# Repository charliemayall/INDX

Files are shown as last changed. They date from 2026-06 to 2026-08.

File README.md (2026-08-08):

# INDX Wiki

> The community knowledge base for the Bondtech INDX, an induction-based automatic tool changer for open-platform XY-head 3D printers.

---

## Table of Contents

**Part 1: What is INDX?**

1. [What is INDX?](#what-is-indx)
2. [How It Works](#how-it-works)
3. [Kits & What's in the Box](#kits--whats-in-the-box)
4. [Supported Printers](#supported-printers)
5. [Technical Specifications](#technical-specifications)
   - [Part Cooling](#part-cooling)

**Part 2: Getting Started**

6. [Requirements & Preparation](#requirements--preparation)
7. [Installation](#installation)
   - [Hardware Installation](#hardware-installation)
   - [Firmware Configuration](#firmware-configuration)
     - [Klipper / Kalico](#klipper)
       - [INDX macro files](#indx-macro-files)
       - [Mainsail RESUME coexistence](#mainsail-resume-coexistence)
       - [Automated dock X measurement](#automated-dock-x-measurement-built-in)
       - [Homing override](#homing-order-important)
     - [RRF (RepRapFirmware)](#rrf-reprapfirmware)
   - [Initial Startup](#initial-startup)

**Part 3: Configuration**

8. [Configuration](#configuration)
   - [Dock Position Calibration](#dock-position-calibration)
     - [Finding dock_y](#finding-dock_y-y-fully-seated-position)
     - [Finding dock_x](#finding-dock_x-x-tool-centre)
   - [Tool Offsets](#tool-offsets)
     - [Method 1: Print and adjust](#method-1-print-and-adjust-free-no-extra-hardware)
     - [Method 2: Nudge](#method-2-nudge-automatic-requires-small-hardware)
     - [Method 3: Nozzle camera + CAL_01/02/03](#method-3-nozzle-camera-most-precise-xy-higher-cost)
     - [Z offset: CAL_Z](#z-offset-calibration)
   - [Temperature & Induction Settings](#temperature--induction-settings)
   - [Speed & Acceleration](#speed--acceleration)

**Part 4: Day-to-day Use**

9. [Using INDX](#using-indx)
   - [Loading Filament into Tools](#loading-filament-into-tools)
   - [Performing Tool Changes](#performing-tool-changes)
   - [Slicer Setup](#slicer-setup)

**Part 5: Designing for INDX**

10. [Designing for INDX](#designing-for-indx)
    - [Dock Design](#dock-design)
    - [Part Cooling (custom)](#part-cooling-1)
    - [CAD Files & Templates](#cad-files--templates)

**Part 6: Maintenance, Support & Community**

11. [Maintenance](#maintenance)
    - [Nozzle clog: cold pull procedure](#nozzle-clog-cold-pull-procedure)
12. [Troubleshooting](#troubleshooting)
13. [FAQ](#faq)
14. [Community & Contributing](#community--contributing)

---

**Part 1: What is INDX?**

---

## What is INDX?

INDX (INduction Dynamic eXtruder) is Bondtech's automatic tool-changer system for FDM 3D printers. It enables printing with multiple materials, colors, or nozzle sizes in a single print, with near-zero purge waste and tool changes in around 14 seconds. Run two tools or ten; scale your setup as far as your build space allows.

Unlike filament-switcher systems, INDX is a true tool changer: each tool carries its own filament directly. There is no shared filament path and no purge block required.

Unlike traditional mechanical tool changers, INDX uses wireless induction heating, so the passive tools contain **no wires, no heaters, no thermistors, and no electronics**. This makes each tool dramatically cheaper and mechanically simpler.

INDX is sold by Bondtech as a **Development Kit** for open CoreXY printers. Prusa Research has built an official first-party integration for the **CORE One** and **CORE One L**, sold directly through Prusa.

| | INDX Development Kit | Prusa CORE One / CORE One L |
|---|---|---|
| **Sold by** | Bondtech ([bondtech.se](https://www.bondtech.se)) | Prusa Research ([prusa3d.com](https://www.prusa3d.com)) |
| **For** | Most CoreXY printers with open firmware | Prusa CORE One / CORE One L |
| **Setup** | Self-managed (community-supported) | Plug-and-play |
| **Smart Head** | See [bondtech.se](https://www.bondtech.se) | See [prusa3d.com](https://www.prusa3d.com/applications/prusa-3d-printers-with-bondtech-indx_243519/) |
| **Passive Tools** | See [bondtech.se](https://www.bondtech.se) | See [prusa3d.com](https://www.prusa3d.com/applications/prusa-3d-printers-with-bondtech-indx_243519/) |

This wiki focuses on the **INDX Development Kit** and community integrations. For the Prusa integration, refer to [Prusa's documentation](https://www.prusa3d.com/applications/prusa-3d-printers-with-bondtech-indx_243519/).

---

## How It Works

INDX is built around two components: a single active **Smart Head** that stays on the gantry, and a set of interchangeable **Thin Passive Tools** parked in a dock.

### Smart Head

The single active unit that travels on the gantry. Contains all expensive and active components:

- **Induction coil (IN)**: wirelessly heats the nozzle of whichever passive tool is currently mounted on the Smart Head.
- **IR thermopile sensor**: reads nozzle temperature without physical contact. Also reports ambient temperature and nozzle surround temperature for monitoring.
- **Dynamic eXtruder (DX)**: self-adjusting dual-drive extruder with automatic tension mechanism.
- **Load cell**: used for sensing tool/nozzle touch.
- All wiring, electronics, and motion stays here; nothing transfers to the passive tools

### Thin Passive Tools

Interchangeable tools parked in a dock within reach of the gantry. Each tool contains a filament path and a specially designed nozzle, and nothing else. No wires, no heaters, no thermistors, no electronics. Heat is delivered wirelessly by the Smart Head's induction coil when the tool is picked up; the tool cools passively when deposited back in the dock.

Two variants are available, both built from hardened steel:

- **CHT (Core Heating Technology)**: splits filament into three strands internally for faster melting and higher flow rates. The standard choice for most materials including abrasive-filled filaments. Available in common sizes.
- **Standard (non-CHT)**: straight-through melt zone with lower back-pressure, optimized for soft flexible filaments (TPU, TPE).

Tools are held in the Smart Head by a high-precision **Maxwell coupling** (a 3-point kinematic coupling that self-aligns the tool to the exact same position every time it is picked up), ensuring micron-level repeatability on every tool change. In practice this means you calibrate your tool offsets once, and they stay correct across thousands of tool changes.

### Tool Change Sequence

1. Smart Head moves to the dock and deposits the current tool
2. Smart Head picks up the next tool
3. Induction coil heats the new nozzle to printing temperature (~4-10 seconds)
4. Printing resumes

**Total tool change time: ~14 seconds**, depending on temperature delta, priming, and travel distance.

Because every material runs in its own dedicated nozzle, there is no cross-contamination between materials; purging is not required. The only material used after a tool change is a small **prime** at the start of printing: when a nozzle heats up, the filament in the melt zone re-melts and pressure needs to be rebuilt before extrusion is consistent. Priming pushes a small amount of filament through to establish that pressure, ensuring the first line of print is correctly extruded. Because each tool also cools passively when separated from the Smart Head, oozing is minimal.

---

## Kits & What's in the Box

### Development Kit

The INDX Development Kit comes as a **base kit** (the core hardware you need to get started) plus **tools** and **accessories** you choose to match your printer and setup.

#### What's in the box

Every Development Kit includes:

| Component | Description |
| --- | --- |
| **Bondtech INDX Smart Head** | The active unit: induction coil, contactless IR temperature sensor, DX extruder, and all electronics. One per printer. **Does not include a Thin Passive Tool**; tools are ordered separately. |
| **Bondtech INDX Link Board** | USB/CAN bridge between your host computer and the Smart Head. Includes 330 mm AWG18 power cables with horseshoe connectors for PSU screw terminals. A USB cable from the Link Board to your host is not included; see [Link Board](#link-board) for requirements. |
| **Crimp & connector kit** | Crimps and connectors for terminating accessories to the Bondtech INDX PCB: part cooling fan, LED, endstop, and USB devices. |

#### Tools

Thin Passive Tools are the interchangeable tool heads that do the actual printing. Choose quantity, nozzle type, and nozzle size when ordering. You need at least one tool to print, and one per material or color you want to run simultaneously.

| Option | Nozzle sizes | Best for |
| --- | --- | --- |
| **CHT (Core Heating Technology)** | 0.4 / 0.5 / 0.6 / 0.8 / 1.0mm | Most materials: PLA, PETG, ABS, ASA, PA, abrasive-filled filaments |
| **Standard (non-CHT)** | 0.25 / 0.4mm | Flexible filaments (TPU, TPE) and sensitive composites |

See [Thin Passive Tools](#thin-passive-tools) in the Technical Specifications for full details on each variant.

#### Accessories

Select the accessories that match your printer when ordering:

| Accessory | Options | Notes |
| --- | --- | ----- |
| **Bondtech INDX Link Cable** | Choose length | XT30 2+2 cable (24V, GND, CAN+, CAN−) with a shield connected to GND on the Link Board, from the Link Board to the Smart Head. Red/black wires carry power, yellow/white carry CAN H/L. Choose the length that fits your wiring run. See note below. |
| **Tool Dock** | Pre-made SLS hardware or STL/STEP files | Bondtech sells ready-made docks for common Makerbeam/1515 extrusion. Or download the files and print your own. |
| **X-Carriage adapter** | MGN12H option for 6mm belts, or download files | Required to mount the Smart Head to your carriage. Available for common CoreXY standards; check the shop or download from GitHub. |

> **What is CAN bus?** CAN bus is a communication standard that lets multiple devices share a single cable. You don't need to understand the protocol in depth; the Link Board handles it for you. In practice it means the Smart Head connects to the Link Board via just one 4-wire cable (carrying both power and data) instead of the bundle of wires a conventional toolhead needs. CAN is currently only supported on RRF; USB is used for Klipper/Kalico.
>
> **Choosing cable length:** Measure the wiring run from your Link Board mounting location to the Smart Head along the actual path the cable will travel (over the gantry, not straight-line). Add some slack. When in doubt, order longer. A cable that is too short cannot be extended, and excess length can be coiled and managed.

> **Integration note:** The Development Kit does not include a pre-configured printer profile or plug-and-play setup. You are responsible for integrating INDX with your printer's firmware and mechanics. The community provides configs and guides for common platforms; see [Supported Printers](#supported-printers) and [Community & Contributing](#community--contributing).

---

## Supported Printers

### First-party integrations

Prusa Research has built an official first-party integration for their CoreXY printers. These are sold and supported directly by Prusa, not through the INDX Development Kit.

| Printer | Status | Notes |
| --- | --- | ----- |
| Prusa CORE One | Available | Sold by Prusa Research. Plug-and-play. Supports up to 8 tools. See [prusa3d.com](https://www.prusa3d.com/applications/prusa-3d-printers-with-bondtech-indx_243519/) for details. |
| Prusa CORE One L | Coming later | First-party Prusa integration, availability timeline TBD. Supports up to 8 tools. |

### Officially supported integrations

Beyond the first-party Prusa integration, Bondtech officially supports a small set of community-built integrations for specific printers. Each comes with ready-to-print parts and the installation files needed to mount INDX on that machine. Download them from the links below.

| Printer | Designer | Files |
| --- | --- | ----- |
| Sovol SV08 OG & SV08 Max | 3DPrintDemon | [Printables](https://www.printables.com/model/1771164-official-indx-sovol-sv08-og-sv08-max-integrations) |
| Voron Trident R2 | Steve — Voron team, designer of the Trident | [Printables](https://www.printables.com/model/1761163-trident-r2-bondtech-indx-mods) |

### Community integrations

INDX runs on a wide range of CoreXY printers, far more than Bondtech could ever test and support directly. What makes that possible is community members who've done the integration work on their own printer and shared what they learned. Every config in the repo started with someone doing it for the first time.

> **What does "community" status mean?** The hardware works on that printer, but the integration guide comes from the community, not Bondtech. Some printers already have complete, verified configs on GitHub; check the repo first. Others are earlier stage. The [Bondtech Discord](https://discord.gg/XDX9jDXN6e) has channels for specific printers, which is a good place to find others running the same platform and see how far along the integration is.

| Printer | Status | Notes |
| --- | --- | ----- |
| Voron 2.4 | Community | |
| Voron Trident | Community | Trident R2 has an [officially supported integration](#officially-supported-integrations) |
| RatRig V-Core | Community | |
| Sovol | Community | SV08 OG / SV08 Max have an [officially supported integration](#officially-supported-integrations) |
| Custom CoreXY | Community | Any CoreXY with open firmware; see [Requirements](#requirements--preparation) |

**Your printer isn't listed?** If you've got INDX running on it, that integration belongs here. Submit a pull request on [github.com/BondtechAB/INDX](https://github.com/BondtechAB/INDX) and you'll save the next person hours of work. See [Contributing a printer integration](#contributing-a-printer-integration) for what to include.

---

## Technical Specifications

*Specifications are preliminary and subject to change.*

### Smart Head

| Specification | Value |
| --- | ----- |
| Maximum operating voltage | 24V |
| Maximum nozzle temperature | 300°C |
| Maximum ambient operating temperature | 60°C |
| Flow rate | 40mm³/s *(measured at 220°C with 25°C ambient; lower rates achievable depending on nozzle size)* |
| Nozzle heat-up time | ~4-8 seconds |
| Tool change time | ~14 seconds *(highly dependent on temperature, priming, and travel distance)* |
| Power consumption | ~60W |
| Tool change mechanism | Maxwell coupling (3-point kinematic) |
| Heater type | Induction coil |
| Temperature sensor | Wireless & contactless IR thermopile |
| Nozzle sensor | Load cell (bi-directional) |
| Extrusion system | Direct Drive |
| Filament pre-tension | Self-adjusting (DX extruder, dual-drive with automatic tensioning) |
| Extruder chassis material | Aluminium |
| Cowling material | SLS-printed PA12 |
| Minimum tool center-to-center distance | 34mm bare; **41mm** with Bondtech part cooling solutions |
| Weight | 345g *(including one tool)* |
| Dimensions | See [reference geometry](#cad-files--templates) |

### Part Cooling

INDX uses a modular part cooling system. Cooling solutions snap onto the outside of the Smart Head cowlings, making it easy to swap between setups without tools. Three options are supported:

| Option | Description |
| --- | --- |
| **Dual 40×10 fans** | Two axial fans mounted symmetrically for balanced airflow around the nozzle |
| **CPAP** | High-flow airflow from a remote CPAP blower unit, routed via a flexible tube to the Smart Head, keeping weight off the gantry |

The right choice depends on your materials and print speed requirements. The dual 40×10 connect to the part cooling fan output on the Bondtech INDX PCB. The CPAP blower is a remote unit mounted elsewhere on the printer and connects to your main board instead; only the airflow tube routes to the Smart Head.

Printable ducts for both options are available in [CAD Files & Templates](#cad-files--templates).

### Bondtech INDX PCB

The Bondtech INDX PCB is mounted inside the Smart Head and is the central electronics board for the system.

**Electronics**

| Specification | Value |
| --- | ----- |
| Stepper driver | TMC2240 |
| Stepper run current | 0.6A |
| Extruder rotation distance | 5.7mm |
| Built-in accelerometer | LIS2DW |
| Built-in rotary encoder | AS5047D (magnetic) |
| Built-in load cell | *(specifications to be confirmed)* |

**Connectors**

| Connector | Pins | Notes |
| --- | ---- | ----- |
| Motor | Coil A+, Coil A−, Coil B+, Coil B− | DX extruder stepper motor |
| Fan | TACHO, FAN+, GND | Supports tachometer feedback |
| LED | 5V (VBUS), NP OUT, GND | NeoPixel compatible |
| Endstop | 3V3, SIGNAL, GND | 3.3V logic level |
| USB | VBUS, DP+, DP−, GND, GND | Supports accessories such as camera or Beacon probe scanner |
| CAN termination jumper | — | Enable/disable CAN bus termination |
| CAN Reset jumper | — | Puts the board into DFU mode for firmware flashing; remove after flashing |
| Communication switch | CAN / USB | Selects between CAN-FD and USB communication modes; must match the switch position on the Link Board |

**Status LEDs**

| Label | Colour | Meaning |
| ----- | --- | --- |
| VIN | Blue | 24V power present |
| 3V3 | Green | 3.3V onboard regulator active |
| ACTIVITY | Green | CAN-FD bus activity (other than regular time-sync messages) |
| STATUS | Red | Flashes at ~1Hz in sync with the main board = CAN time sync OK; rapid continuous flashing = no CAN sync; startup error codes (see table below) |

On first boot or after a failed flash, the STATUS LED may flash a startup error code rather than the normal 1Hz pattern. The pattern is: slow blinks (group 1) pause, then fast blinks (group 2). If this happens, reflash the firmware.

**Startup error codes**

| Error | Slow blinks | Fast blinks | Description |
| ----- | --- | --- | --- |
| ErrorTempMin | 1 | 1 | Measured temperature too low |
| ErrorTempMax | 1 | 2 | Measured temperature too high |
| ErrorTempAmbientMin | 1 | 3 | Ambient temperature too low |
| ErrorTempAmbientMax | 1 | 4 | Ambient temperature too high |
| ErrorTempDiff | 1 | 5 | Requested temperature differs significantly from measured temperature |
| ErrorHeatMax | 2 | 1 | Heater on at max power for too long |
| ErrorHeatInput | 2 | 2 | Heater enable request active for too long |
| ErrorInternalTemp | 5 | 3 | IR sensor self-test failed at boot |
| ErrorInternalUart | 5 | 4 | Internal UART fault |
| ErrorInternalEnable | 5 | 5 | Internal enable fault |

**Front INDX LED states**

The Smart Head uses a NeoPixel-compatible LED array on the front face to communicate its current state during normal operation. These are the same LEDs that display startup error codes.

| State | Colour | Pattern |
| ----- | --- | --- |
| Heating | Amber (RGB 255, 191, 0) | Breathing at 0.5 Hz (sine); brightness starts at 0 and increases as temperature approaches target |
| Cold / at ambient | Green | Solid |
| At target temperature | Amber | Solid |
| Cooling down from hot | Blue | Solid |
| DFU (firmware update) mode | Blue | Blinking |
| Load cell transient (filament gripped) | Purple | Single fast flash (~200 ms), then returns to previous state; effect is suppressed while the stepper motor is energised |

**FFC cable warning**

The Smart Head contains two PCBs (INDX VF PCB and INDX MCU PCB) connected by 20-way FFC (Flexible Flat Cable) connectors. If you ever need to disconnect and reconnect them during servicing:

- Insert the cable straight; inserting at an angle is easy to do and will short pins. Powering up with a shorted FFC will likely damage the board.
- The latch direction on the INDX MCU PCB FFCs is counter-intuitive: the latch is **unlocked when up**. After inserting the cable, push the latch **down toward the PCB** to lock it.

### Link Board

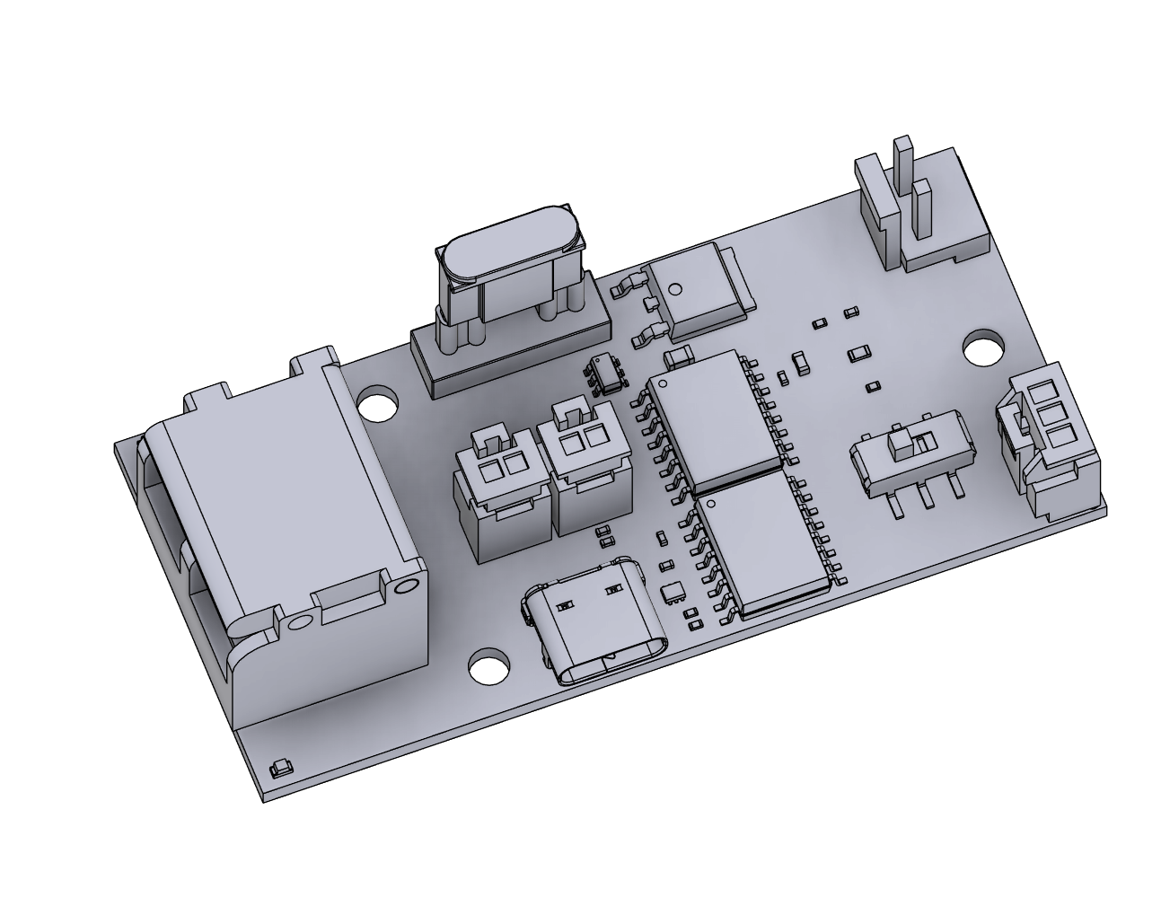
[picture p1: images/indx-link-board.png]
Bondtech INDX Link Board


The Link Board is a required component of every INDX Development Kit setup. It sits between your host computer and the Smart Head, acting as the USB/CAN bridge and providing several protection features that make the connection stable and safe.

**Why the Link Board is required**

The Link Board caps USB communication speed to **12 Mbps (Full Speed)**. While this is lower than the theoretical USB 2.0 maximum, it is intentional: Full Speed USB is dramatically more stable in electrically noisy printer environments than High Speed (480 Mbps). In practice this means fewer dropouts and disconnects, and a much more reliable connection to the Smart Head.

**Protection features**

| Feature | What it does |
| --- | --- |
| **USB isolator** | Electrically isolates the Smart Head from your host computer. Any electrical fault or noise on the printer side cannot travel back through the USB cable to your Raspberry Pi or PC. |
| **Reverse polarity protection** | Prevents damage if the 24V power input is connected with reversed polarity. |
| **4A fuse** | Protects the power input. If something goes wrong on the 24V side, the fuse blows before damage can propagate further. |

**Communication switch**

The Link Board has a switch to select between **USB** and **CAN** communication modes. This must match the switch position on the INDX MCU PCB inside the Smart Head — both boards must be set to the same mode, or the connection will not work. See [Switch configuration](#3-wiring) for reference images showing the correct switch positions on the Smart Head side.

**USB cable (not included)**

A USB cable from the Link Board to your host computer is not included and must be sourced separately. Requirements:

- **Data cable, not a charge-only cable.** Charge-only cables omit the data lines entirely and will not work. Verify the cable is rated for data transfer before using it.
- **Correct impedance.** The cable must meet USB signal integrity requirements. Cheap or poorly made cables can cause dropouts even at Full Speed. Use a cable from a reputable brand.
- **Total USB run ≤ 2 meters.** The combined length of your USB cable (host to Link Board) and your INDX Link cable (Link Board to Smart Head) must not exceed 2 meters. Plan your cable routing and Link cable length selection with this in mind.

**Specifications**

| Specification | Value |
| --- | ----- |
| Host connection | USB-C |
| Printer-side connection | Link cable to Bondtech INDX PCB |
| Input power | 24V + GND from PSU |
| Included power cables | AWG18, 330mm, horseshoe connectors for PSU screw terminals |
| USB speed | 12 Mbps (Full Speed) |
| Fuse rating | 4A |
| Max total USB run | 2 meters (USB cable + Link cable combined) |

### Thin Passive Tools

All Thin Passive Tools are built from hardened steel, contain no electronics or wiring, and use induction heating via the Smart Head. Two variants are available:

**CHT (Core Heating Technology): Standard choice for most materials**

Uses Bondtech's patented CHT internal geometry, which splits filament into three thinner strands for faster melting and higher flow rates. Recommended for PLA, PETG, ABS, ASA, PA, and abrasive-filled filaments (Carbon Fiber, Glass Fiber). Not recommended for soft flexible filaments.

| Specification | Value |
| --- | ----- |
| Available nozzle sizes | 0.4 / 0.5 / 0.6 / 0.8 / 1.0mm |
| Material | Hardened steel |
| Compatible filament diameter | 1.75mm |
| Maximum nozzle temperature | 300°C |
| Electronics | None |
| Weight | 25g |

**Standard (non-CHT): For flexible and sensitive materials**

Uses a straight-through melt zone with minimal back-pressure, specifically optimized for soft flexible filaments (TPU, TPE) and sensitive composites. Built to the same hardened steel standard, so it handles abrasive filaments equally well.

| Specification | Value |
| --- | ----- |
| Available nozzle sizes | 0.25 / 0.4mm |
| Material | Hardened steel |
| Compatible filament diameter | 1.75mm |
| Maximum nozzle temperature | 300°C |
| Electronics | None |
| Weight | 25g |

---

**Part 2: Getting Started**

---

## Requirements & Preparation

If you've built a Voron or a similar CoreXY printer from scratch, you have the skills needed to install INDX. The process involves editing Klipper config files, SSH access to your host computer, and careful mechanical alignment. Nothing beyond what a first-time Voron builder will have already done.

### Printer Requirements

For the Development Kit, your printer must meet these minimum requirements:

- **Motion system:** CoreXY, H-bot, Markforged, Cartesian XY-head, or similar. Supported: any motion system where the toolhead moves in XY and Z is handled by the bed or gantry — i.e. CoreXY (not cross-gantry), H-bot, Markforged, and independent-axis Cartesian (XY-head, e.g. Ender 5). Not supported: bed-slinger Cartesian (XZ-head), where the bed moves in Y, or Positron-style machines.
- **Firmware:** Kalico (recommended — native INDX support built in), Klipper, or RepRap Firmware (RRF)
- **Gantry clearance:** 50mm X, 44mm Y. Total toolhead height is ~152mm including strain relief. Additional clearance is required for umbilical and filament management.
- **Dock mounting area:** Each dock is ~70mm tall, 28.5mm wide (X), and 25mm deep (Y). Minimum tool center-to-center spacing is 34mm bare, or 41mm when using the Bondtech part cooling solutions.
- **Wiring:** 24V from the PSU to the Link Board (AWG18 horseshoe-connector cables included). Host computer to Link Board via USB-C or CAN. Link Board to Smart Head via INDX Link Cable (XT30 2+2, carries 24V, GND, CAN+/−, and shield).
- **Print volume impact:** Depends on printer geometry. Printers with sufficient Y overtravel may lose nothing. With a well-designed integration the worst case is 28.5mm of Y travel; avoid designs that exceed this.

### Electrical Requirements

INDX uses two boards: the **Bondtech INDX PCB** (inside the Smart Head) and the **INDX Link Board**.

**Bondtech INDX PCB**

The Bondtech INDX PCB is the central electronics board inside the Smart Head. It consists of two parts connected internally:

- **INDX VF PCB**: handles induction heating, contactless IR temperature sensing, and the heatsink fan
- **INDX MCU PCB**: handles all processing and communication: extruder motor control, accelerometer, load cell, CAN-FD communication, and the external connectors

All electronics are pre-installed inside the Smart Head; no internal wiring required. The Smart Head connects to the Link Board via a single INDX Link Cable (24V, GND, CAN H/DP+, CAN L/DN−, shield to GND) and exposes the following connectors:

- **Motor**: 4-pin, drives the DX extruder (TMC2240 driver). Pin 1 Coil A+, Pin 2 Coil A−, Pin 3 Coil B+, Pin 4 Coil B−
- **Endstop**: 3-pin, 3.3V logic level. Pin 1 3V3, Pin 2 SIGNAL, Pin 3 GND
- **Fan**: 3-pin, supports tachometer feedback. Pin 1 TACHO, Pin 2 FAN+ (PWM 24V), Pin 3 GND
- **LED**: 3-pin NeoPixel. Pin 1 5V (VBUS), Pin 2 NP OUT, Pin 3 GND
- **USB**: 5-pin, supports accessories such as a camera or Beacon probe scanner. Pin 1 VBUS (5V), Pin 2 DP+, Pin 3 DP−, Pin 4 GND, Pin 5 GND
- **Built-in accelerometer**: for resonance measurement and automatic input shaper calibration in Klipper
- **CAN termination jumper**: fitting the jumper enables the 120 Ω end-of-line termination resistor. Fit only on boards at the physical ends of the CAN bus.
- **CAN reset jumper**: Klipper: short the jumper to enter DFU mode for flashing. RRF: fit the jumper for CAN reset (also resets the CAN address). See the [Duet INDX Toolboard documentation](https://docs.duet3d.com/en/Duet3D_hardware/Duet_3_family/INDX_Toolboard).
- **Status LEDs**: 3V3, VIN, STATUS, ACTIVITY

Induction heating and contactless IR temperature sensing are handled internally by the INDX VF PCB; no additional wiring or configuration needed.

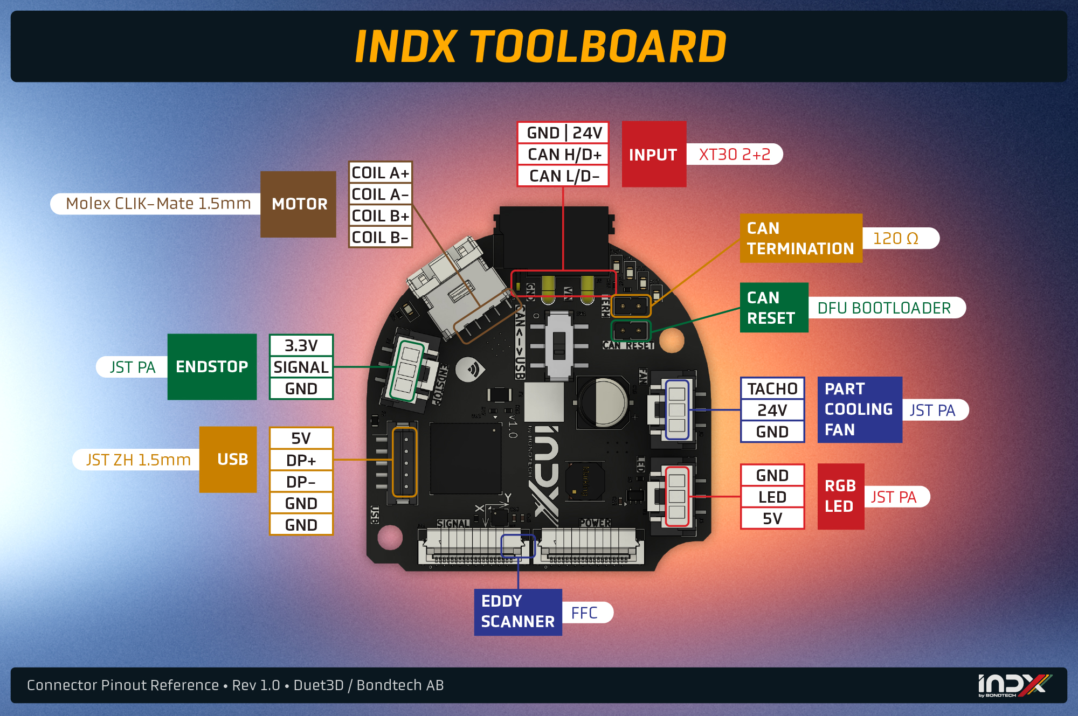
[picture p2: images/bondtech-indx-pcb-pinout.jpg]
Bondtech INDX PCB pinout


**Klipper pin → port mapping** (not exposed in RRF)

| Function | Port(s) |
| --- | --- |
| Motor | STEP `PB12` · DIR `PB23` · ENN `PB4` · CS `PA10` · SPI1 SCLK `PA5` / MOSI `PA4` / MISO `PA7` |
| Endstop | `PA9` |
| Part cooling fan | FAN `PA1` · TACHO `PA0` |
| Heatsink fan | FAN0 `PA21` · TACHO `PA20` |
| Neopixel | `PA8` |
| Eddy scanner | ldc_int `PB10` · ldc_clk `PB11` · temp_ldc `PB9` |

**Link Board**

The Link Board is required and bridges your host computer to the Smart Head. For full details on protection features, the communication switch, and USB cable requirements, see [Link Board](#link-board) in the Technical Specifications.

For wiring purposes:

- Requires **24V and GND** from your printer's power supply; connect using the included power cables (AWG18, 330 mm, pre-terminated with horseshoe connectors for screw terminal PSUs)
- Connects to the Smart Head via the INDX Link Cable
- Connects to your host computer via USB (cable not included — see [Link Board](#link-board) for requirements)
- The communication switch on the Link Board must match the switch on the INDX MCU PCB; both must be set to the same mode

**Power**

- The system runs on **24V**
- The Link Board is powered by a direct 24V/GND connection from your PSU
- Power is then passed through the Link cable (24V, GND, CAN+/D+, CAN−/D-) from the Link Board to the Smart Head; no additional PSU connection needed at the Smart Head

**Mainboard compatibility**

- Works with any printer running a Raspberry Pi, similar host computer or Duet board
- The Link Board connects to the host via CAN/USB; the host handles CAN/USB communication to the Bondtech INDX PCB

### Software Requirements

- **Kalico (recommended):** native INDX support is built in — nothing to install on the host, and the MCU firmware ships with Kalico. See [Firmware Configuration](#klipper).
- **Klipper (mainline):** add the [`indx_klipper`](https://github.com/BondtechAB/indx_klipper) module (installed with its `install.sh`), which brings the same INDX support to a stock Klipper install. See [Firmware Configuration](#klipper).
- RRF: RepRapFirmware **3.7.0-alpha (2026-02-10) or later**, required on both the main board and the Bondtech INDX PCB.
- Slicer: Any slicer with multi-filament or multi-color support

### Tools Required

| Tool | Use |
| ---- | --- |
| Hex keys | Smart Head, X-carriage adapter, and dock mounting |
| Crimping tool | Optional; only needed if connecting accessories (fan, LED, endstop, or USB devices) to the Bondtech INDX PCB |

### Skills Assumed

- Editing Klipper config files (`.cfg` syntax, adding sections, restarting Klipper)
- SSH access to your host computer (the [Connect via SSH](#connect-to-your-printer-via-ssh) section covers this if you need a refresher)
- Crimping JST and similar connectors

### What to Have Ready Before Starting

- A working printer, homed, printing, and confirmed stable before you begin
- Kalico (or Klipper / RRF) installed and running on your host computer
- SSH access to your host computer confirmed
- Spool holders and filament routing planned for the number of tools you intend to run

---

## Installation

> **Note:** These are general installation guidelines using the Bondtech-sold hardware as an example. Because INDX works across many different CoreXY printers, exact details (screw sizes, adapter geometry, carriage type, dock placement) will vary by printer. For printer-specific integration guides, check the [github.com/BondtechAB/INDX](https://github.com/BondtechAB/INDX) repository and the community resources in [Community & Contributing](#community--contributing).

### Hardware Installation

#### 1. Install the Smart Head

The Smart Head replaces your printer's existing toolhead entirely. It mounts to the X-axis carriage using a two-part system:

1. **X-carriage adapter**: bolts onto your carriage
2. **Smart Head**: attaches to the X-carriage adapter with 4 bolts

**X-carriage adapters** are available in two ways:

| Source | Material | Notes |
| --- | --- | --- |
| Bondtech (shop) | SLS-printed Nylon 12 GF | Common MGN12 carriage options available to purchase |
| GitHub / community | User-printed | STL/STEP files on [github.com/BondtechAB/INDX](https://github.com/BondtechAB/INDX); print your own for less common setups |

If your carriage configuration isn't covered by Bondtech's sold options, check the GitHub repo for a community-contributed adapter or print your own from the provided files. A printable MGN12H adapter (6mm belts) is available in [CAD Files & Templates](#cad-files--templates). Community-made X-carriage designs that meet quality standards will be included in the official repo. If you're designing your own, see [CAD Files & Templates](#cad-files--templates) for the reference geometry files.

> **Before you start:** Remove your existing hotend, part cooling fan, and any toolhead PCB or wiring mounted on the carriage. The Smart Head replaces all of this.

**Step 1: Mount the X-carriage adapter to the carriage**

Route and attach the belts behind the X-carriage, then attach the X-carriage adapter to your carriage block using the screws specified for your adapter. Tighten firmly but do not overtighten.

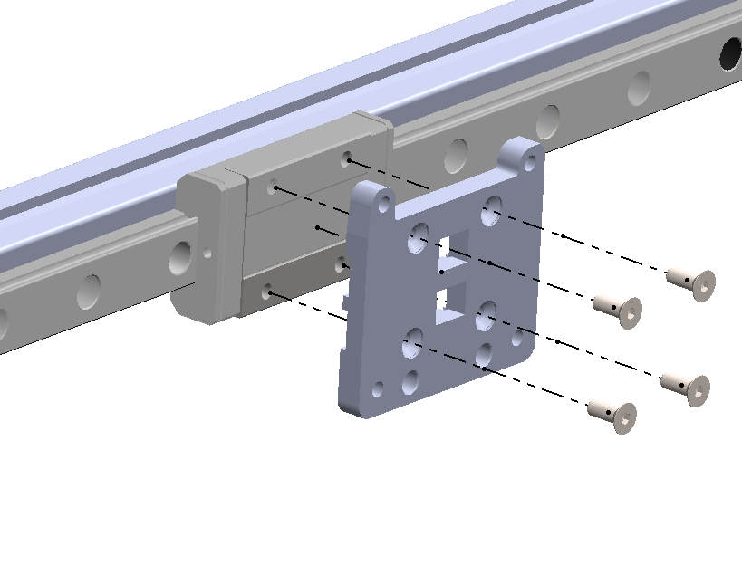
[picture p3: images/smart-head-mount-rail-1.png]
INDX MGN12H adapter mounting to rail, exploded view


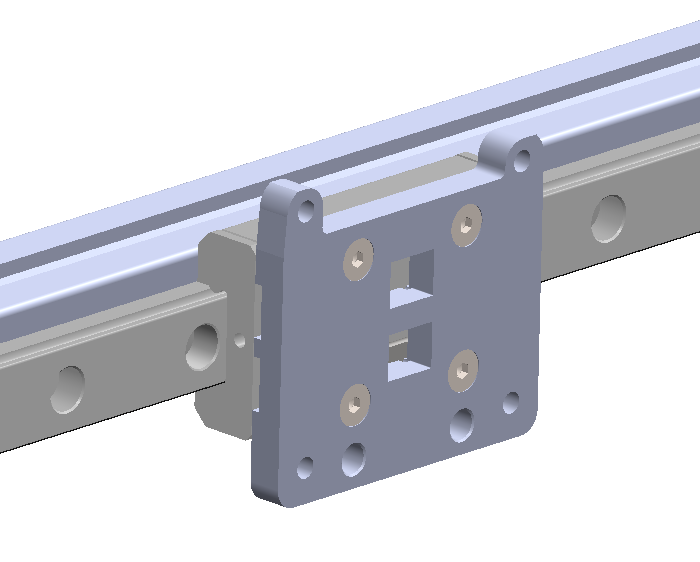
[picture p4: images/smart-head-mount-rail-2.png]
INDX MGN12H adapter mounted on rail


**Step 2: Place the Smart Head onto the adapter**

Slide the Smart Head onto the X-carriage adapter so the mounting faces are flush.

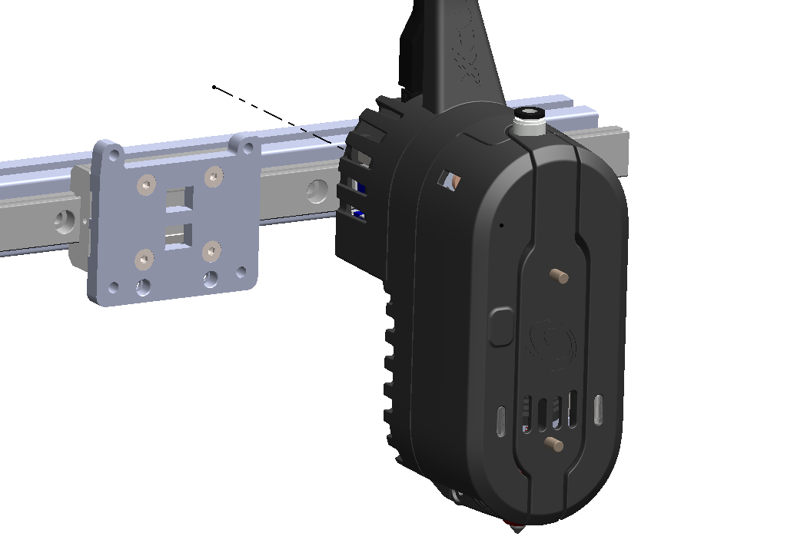
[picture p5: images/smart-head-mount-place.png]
Smart Head placed on X-carriage adapter


**Step 3: Secure the Smart Head**

Fasten the Smart Head to the adapter using 4 screws as specified for your adapter. Tighten firmly but do not overtighten.

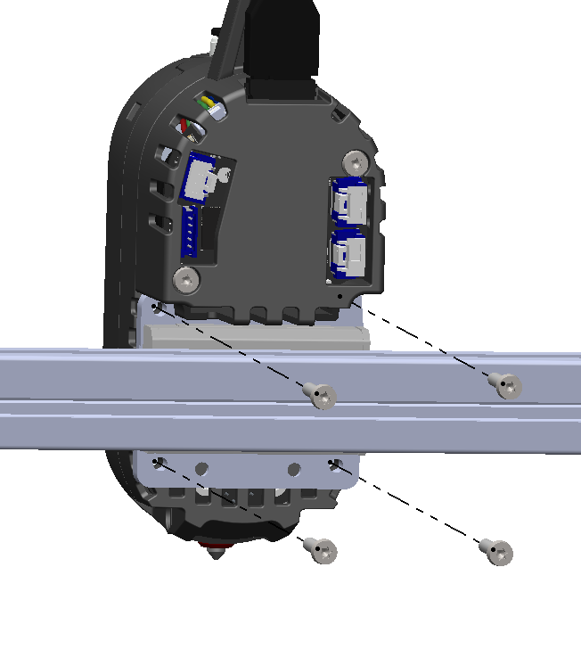
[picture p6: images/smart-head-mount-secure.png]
Smart Head secured, rear view


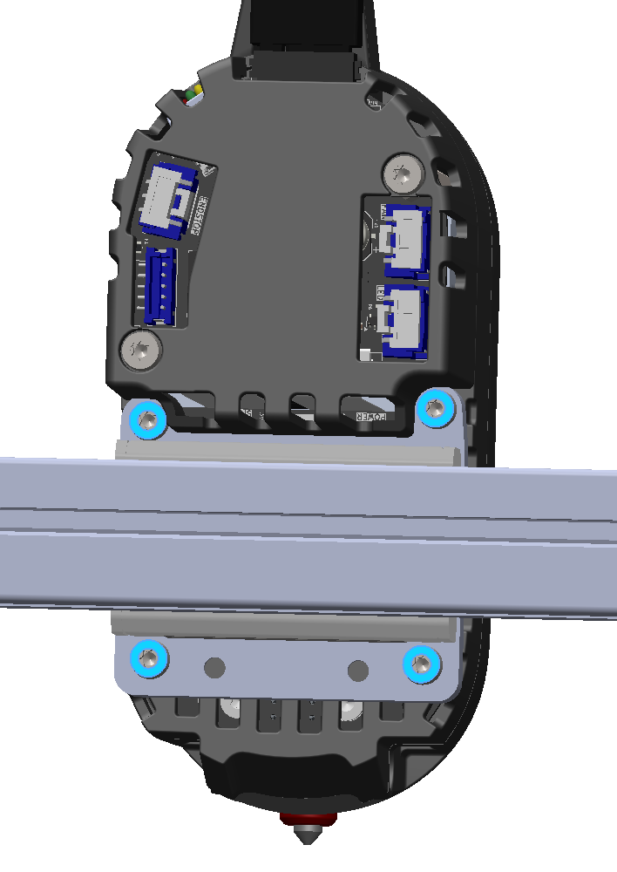
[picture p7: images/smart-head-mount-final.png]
Smart Head fully installed, front view


The Smart Head is now installed on the carriage.

**Attach part cooling**

Part cooling solutions snap onto the outside of the Smart Head cowlings. Attach your chosen cooling solution now before mounting the dock.

**Installing the fan shroud clip**

1. Loosen the screw that holds the INDX Front Cover.

   Loosen front cover screw

2. Use an M3×8 screw to secure the INDX Front Cover together with the fan shroud clip.

   Fan shroud clip installed

3. With the clip installed, attach the fan shroud to the Front Cover. The shroud has an upper tab that locates into a slot at the top of the Front Cover (highlighted in blue). Align the tab with the slot, then rotate the bottom of the shroud inward until it seats in position.

   Fan shroud mounted

#### 2. Mount the Dock

The dock can be positioned anywhere within the gantry's travel range, but the Smart Head must be able to face the docked tools directly to pick them up. The right location depends on your printer's layout.

**Frame requirement**

The dock must be mounted to a rigid bar or frame element; the dock hardware alone cannot be free-standing. Most CoreXY printers have an extrusion or crossbar that works for this. If your printer does not have a suitable mounting point, you will need to add one before proceeding.

The Bondtech-sold dock hardware is designed to mount on **15×15 aluminium extrusion**. If you are printing your own dock from the GitHub files, design your mounting to suit your frame.

> ⚠️ **Critical:** The dock has strict positioning requirements that must be met for reliable tool changes. Incorrect placement will cause failed pickups. See the critical requirements below before mounting.

**Dock options:**

| Source | Type | Mounting |
| --- | --- | --- |
| Bondtech (shop) | SLS-printed Nylon 12 GF | Common options for 15×15 aluminium extrusion |
| GitHub | Reference design + community designs | Print yourself, or adapt for your frame |

Community-contributed dock designs will be added to [github.com/BondtechAB/INDX](https://github.com/BondtechAB/INDX) as they are developed. If you design a dock for an unlisted printer or frame, consider submitting it. See [Dock Design](#dock-design) for geometry constraints and design requirements before you start.

**Critical dock positioning requirements**

**Height**

The dock must be positioned so that a parked tool sits **2mm higher** than it does when held in the Smart Head. This offset is what allows the Smart Head to pick up and deposit tools cleanly.

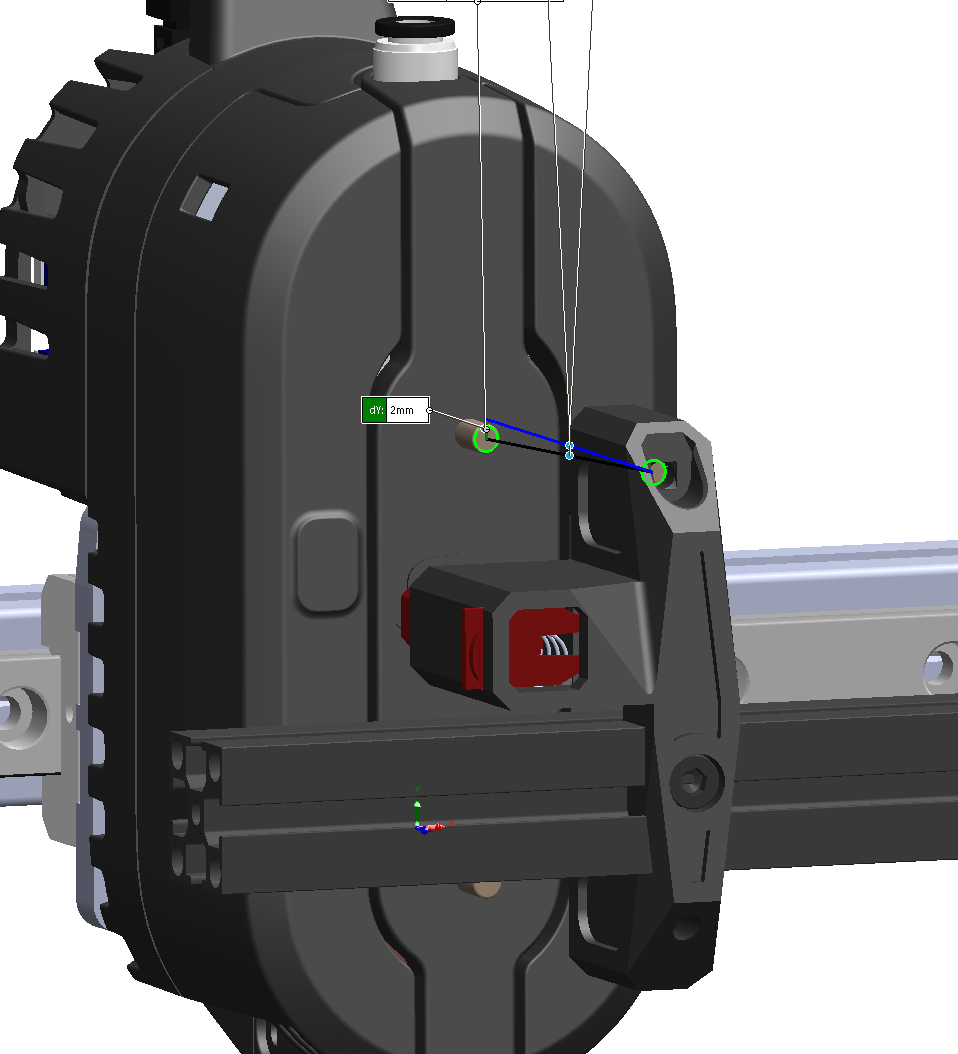
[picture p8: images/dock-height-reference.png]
Dock height reference: 2mm offset between docked and picked-up tool position


**Alignment method**

Use the printable alignment jig ([`INDX_Dock_calibration_tool.stl`](CAD/STL/INDX_Dock_calibration_tool.stl)) placed over the nozzle tool in the toolhead to set the correct height. The printer does not need to be powered on for this step; you are setting the physical dock height manually.

1. Place the printed alignment jig over the tool magnets while the tool is in the smart head.

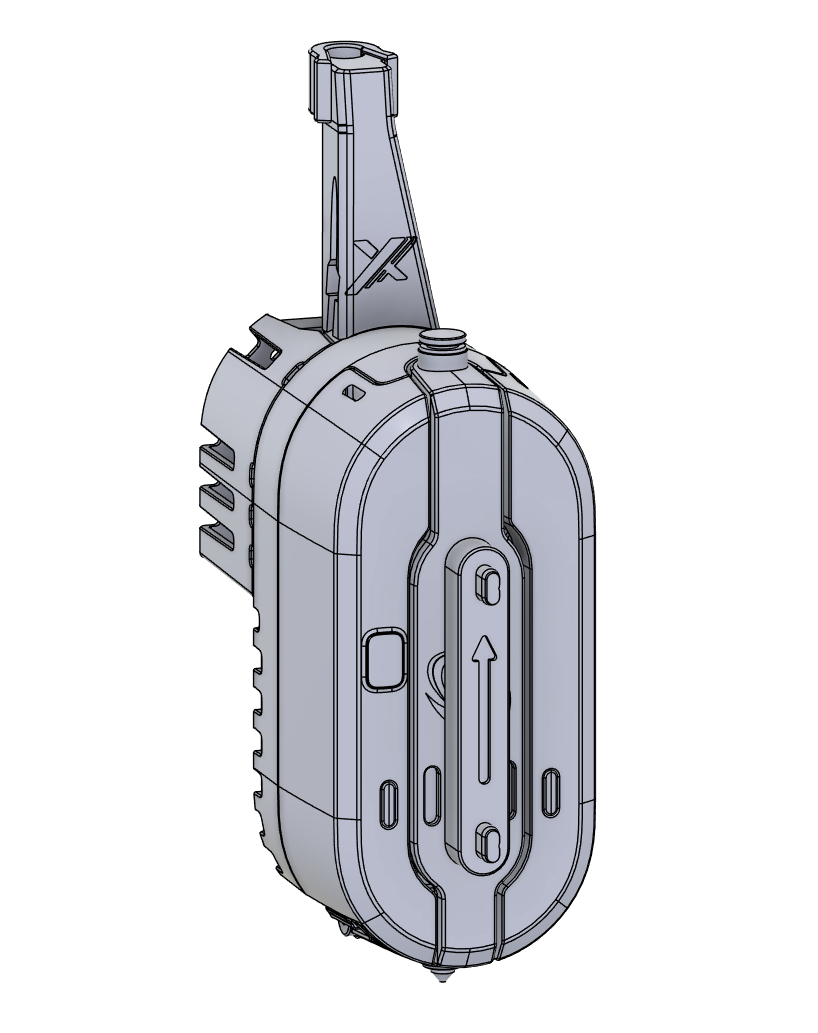
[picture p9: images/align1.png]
Extra magnet placed on the INDX front trigger surface
   

2. Loosen the bar holding screws in order to let it be adjusted up and down, then slide the smart head toward the tool dock and make sure the alignment jig enters the magnet holes smoothly without the smart head nodding from mechanical strain.

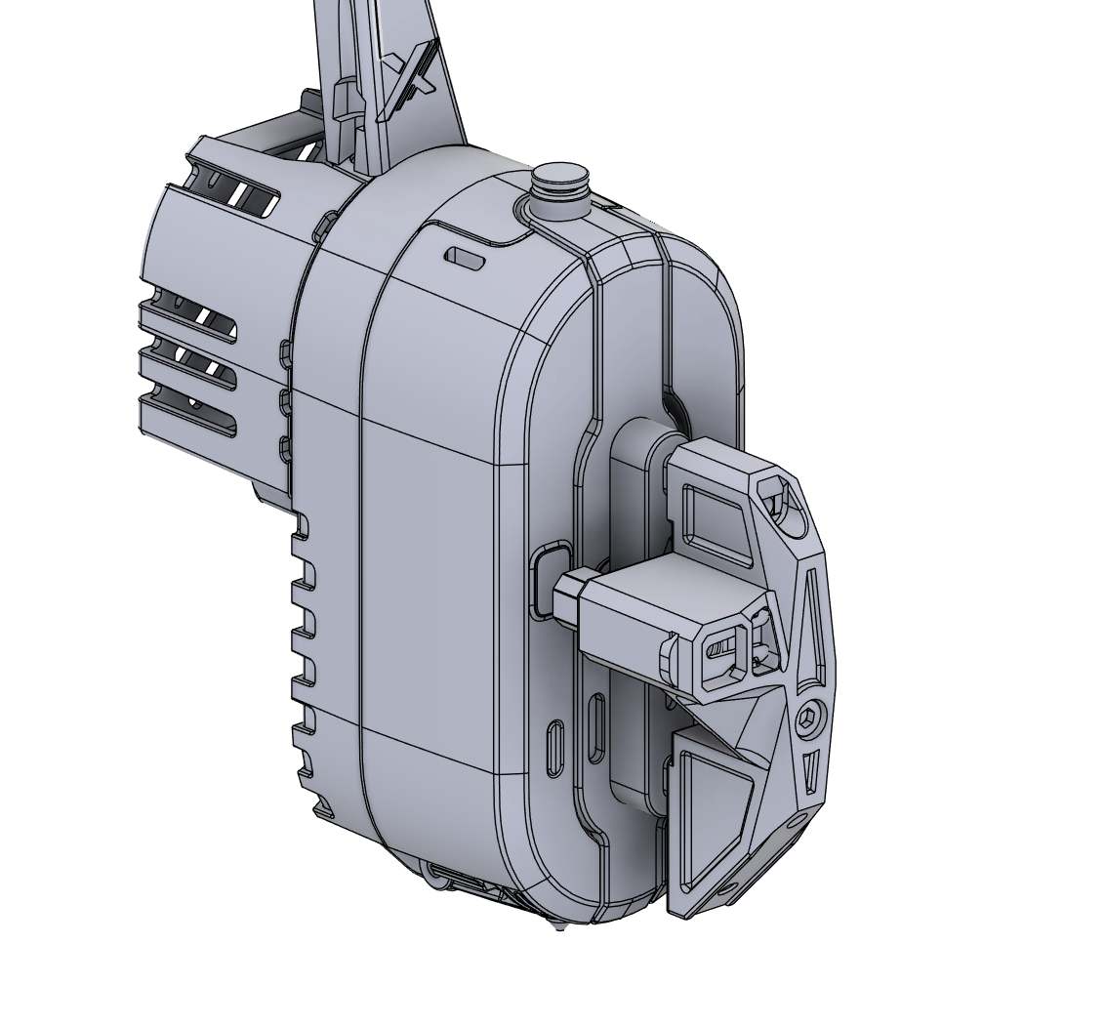
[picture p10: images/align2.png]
Magnet aligned with tool holder magnet
   

3. Secure the dock bar at that height

#### 3. Wiring

Wiring up the Smart Head is unusually simple for a toolhead. On a conventional setup, you're running individual wires for the heater cartridge, thermistor, hotend fan, stepper motor, and any probes or sensors, each terminated, routed, and managed separately. With INDX, all of that is internal: the induction coil, IR temperature sensor, and heatsink fan are all handled inside the Smart Head with no external connections required. The only cable you run to the Smart Head is a single INDX Link Cable, four wires carrying 24V power and data.

The included **Link Board** acts as the bridge between your host computer and the Smart Head. Your host computer connects to the Link Board via USB (cable not included — see [Link Board](#link-board) for requirements), the Link Board connects to the Smart Head via the INDX Link Cable, and the Link Board receives 24V power from the PSU via the included AWG18 cables. That's the entire wiring run.

**Overview of connections:**

```
24V PSU ──────────────────────────────────────────────┐
                                                       │ 24V + GND
Raspberry Pi / host computer                           ▼
    │                                             Link Board
    └── USB ──────────────────────────────────────────►│
                                                       │
                                                       └── Link cable (24V, GND, CAN H/DP+, CAN L/DN−) ──► Bondtech INDX PCB (inside Smart Head)
                                                                                                           │
                                                                                                           ├── Motor (Coil A+, Coil A−, Coil B+, Coil B−)
                                                                                                           ├── Fan (TACHO, FAN+, GND)
                                                                                                           ├── LED (5V, NP OUT, GND)
                                                                                                           ├── Endstop (3V3, SIGNAL, GND)
                                                                                                           └── USB (VBUS, DP+, DP−, GND, GND)
```

**Switch configuration**

Before connecting the Link cable, set the communication mode switches on **both boards** to match: the switch on the INDX MCU PCB inside the Smart Head, and the switch on the Link Board. Both must be set to the same mode or the connection will not work.

Set both switches to **CAN** if you are using RRF. Set both to **USB** if you are using Klipper or Kalico.

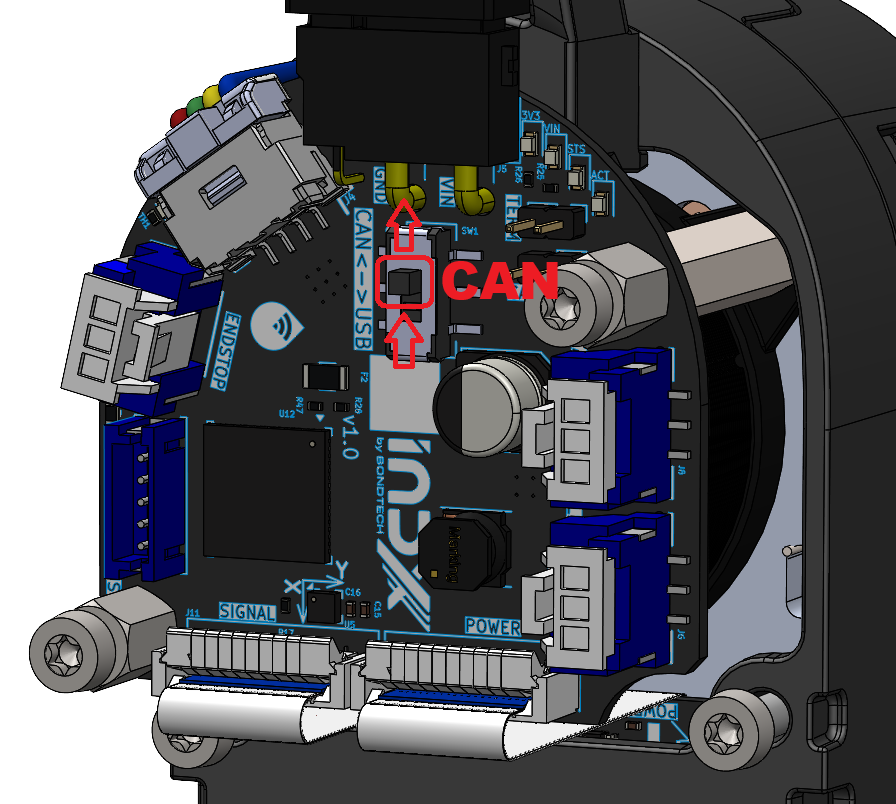
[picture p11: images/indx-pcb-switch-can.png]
INDX MCU PCB switch set to CAN mode

*Switch set to CAN mode*

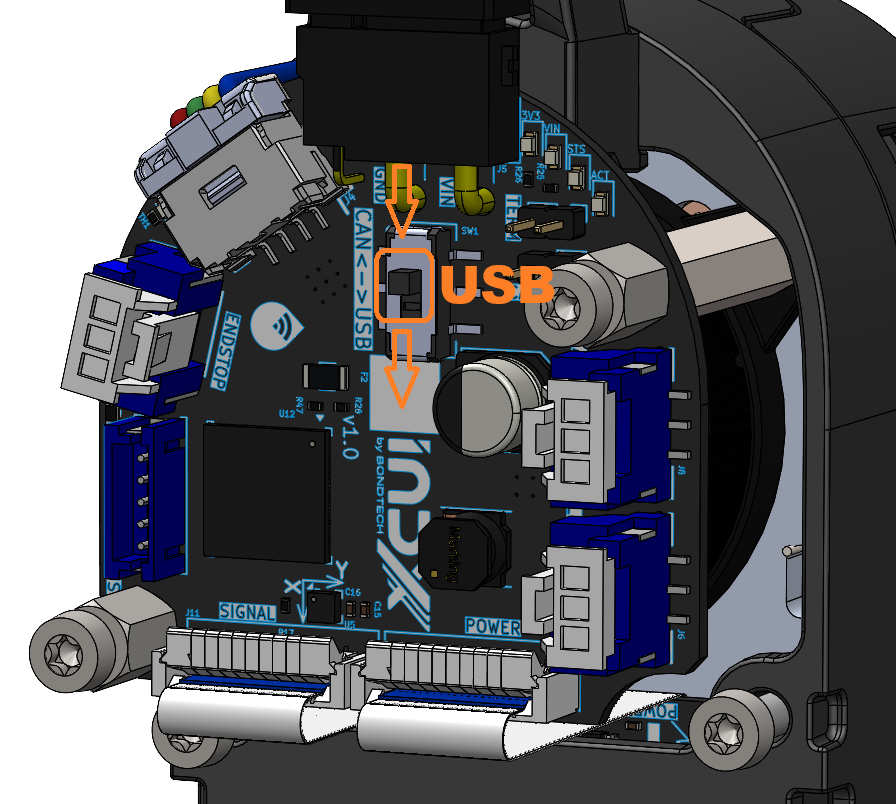
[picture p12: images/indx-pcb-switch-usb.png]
INDX MCU PCB switch set to USB mode

*Switch set to USB mode*

#### 4. Flash the Bondtech INDX PCB

The Bondtech INDX PCB needs to be flashed with the correct firmware before the Smart Head can communicate with your printer. The flashing process differs depending on your firmware; follow the section for your setup.

##### Klipper / Kalico

Flashing is done over SSH from your computer into the Raspberry Pi (or other host computer) running Kalico or Klipper.

**What you need**

- **PuTTY**: a free SSH client for Windows. Download it from [putty.org](https://www.putty.org/).
- Your printer's **IP address**: find this in your router's device list, or check the display on your host if it shows one. You can also use the hostname (e.g. `mainsailos.local` or `fluidd.local`) if your network supports it.

###### Connect to your printer via SSH

1. Open PuTTY
2. Enter your printer's IP address (or hostname) in the **Host Name** field
3. Make sure **Port** is set to `22` and **Connection type** is `SSH`
4. Click **Open**
5. Log in with your printer host credentials; the default username for most Klipper distributions is `pi` (Mainsail OS / FluiddPI) with the password you set during setup

You should now have a terminal prompt on your printer's host computer.

**Enter the bootloader**

Flashing happens while the Bondtech INDX PCB is in bootloader mode. If the board already has firmware, put it into the bootloader by fitting the **CAN RESET jumper** on the INDX MCU PCB while powering the board up. In bootloader mode the board enumerates on the host as a Microchip USB device (vendor `04d8`, product `e483`), identified as **"INDX Toolboard Bootloader"** by Bondtech AB. Confirm it is present with:

```bash
lsusb | grep 04d8:e483
```

**Kalico (recommended)**

Kalico ships with native INDX support built in — both the host module and the MCU firmware are part of the Kalico source tree, so there is nothing extra to install. Build and flash from your Kalico directory (usually `~/klipper`):

```bash
cd ~/klipper
KCONFIG_CONFIG=board_configs/bondtech_indx_usb.config make
KCONFIG_CONFIG=board_configs/bondtech_indx_usb.config make flash FLASH_DEVICE=04d8:e483
```

The `board_configs/bondtech_indx_usb.config` build config is included with Kalico. It preselects the SAME51 MCU, USB communication, and the INDX heater feature, so you don't need to run `make menuconfig`.

**Klipper (mainline)**

Mainline Klipper does not include INDX support. Add it with the `indx_klipper` module, then build and flash:

```bash
git clone https://github.com/BondtechAB/indx_klipper.git
cd indx_klipper
./install.sh /home/pi/klipper        # adjust the path to your Klipper install
make
make flash FLASH_DEVICE=04d8:e483
```

Once flashing is complete, remove the CAN RESET jumper (if you fitted one), power-cycle the Smart Head, and proceed to firmware configuration.

##### RRF (RepRapFirmware)

For RRF, flash and configure the Bondtech INDX PCB following the [Duet INDX Toolboard documentation](https://docs.duet3d.com/en/Duet3D_hardware/Duet_3_family/INDX_Toolboard).

#### 5. Load Passive Tools into the Dock

**Verify the Tool Dock Activator**

Before loading tools, check that the Tool Dock Activator is correctly installed. It is a small bracket mounted upright on the 15×15 mm aluminium extrusion using an M3×10 screw and an M3 nut. It must be perfectly vertical; this is the component that triggers the INDX latch mechanism during pickup.

Tool Dock Activator mounted on extrusion

Check that it is perpendicular to the extrusion:

Tool Dock Activator vertical alignment

**Load tools into the dock**

One passive tool fits in one dock position. Tools are retained by 3×8 mm bar magnets embedded in both the tool and the dock. The magnets naturally guide the tool into the correct orientation as you bring it close; follow the magnetic pull to seat it.

Passive tool loaded in dock

> **Note:** You will set the exact dock position coordinates (`dock_y` and `t*_x`) during the calibration steps later. For now, just seat the tools; the INDX macros handle the rest once configured.

---

### Firmware Configuration

#### Klipper

INDX's host-side support provides everything your printer needs to talk to the Smart Head: the `indx` temperature sensor, induction-heater control, extruder and accessory pin mapping, and the calibration commands. How you add it depends on your firmware:

- **Kalico (recommended):** support is **built in**. There is nothing to install on the host — the `[indx]` object and the `indx` sensor type are part of Kalico, and the MCU firmware ships with it too. Once you've flashed the Bondtech INDX PCB from the Kalico tree (see [Flash the Bondtech INDX PCB](#4-flash-the-bondtech-indx-pcb)), go straight to configuring your printer.
- **Klipper (mainline):** install the [`indx_klipper`](https://github.com/BondtechAB/indx_klipper) module, which adds the same host-side support to a stock Klipper install. Clone it and run its `install.sh` (see [Flash the Bondtech INDX PCB](#4-flash-the-bondtech-indx-pcb) for the commands).

The tool-change and calibration **macros** (`T0`/`T1`…, `PARK_TOOL`, the `CAL_*` helpers) are provided by the INDX macro package — see [INDX macro files](#indx-macro-files).

**Configure your printer**

After installing the plugin, add your INDX configuration to `printer.cfg`:

Add the following to your `printer.cfg`. The `serial` path under `[mcu indxmcu]` will be unique to your board; see the note below on how to find it.

```ini
[mcu indxmcu]
# Replace the serial path below with the one from your board — see "Finding your serial path" below
serial: /dev/serial/by-id/usb-Bondtech_INDX_<your-serial-here>

[indx]
mcu: indxmcu

# These are control parameters for the induction heater — leave them at these values
pid_kp: 1.0
pid_ti: 0.0
pid_td: 0.0
pid_b: 1.0

[extruder]
sensor_type: indx  # Custom sensor type provided by the INDX plugin — reads temperature via the IR sensor on the induction board
min_temp: 0
max_temp: 350

heater_pin: indx:heater
# Induction heating uses watermark (on/off bang-bang) control, not PID.
# This works well for induction because of its very fast response time. Do not change to pid.
control: watermark
nozzle_diameter: 0.4     # Change to match your passive tool nozzle size (0.4 / 0.6 / 0.8 / 1.0)
filament_diameter: 1.75

step_pin: indxmcu:motor_step
dir_pin: indxmcu:motor_dir  # If filament feeds backwards, change to: !indxmcu:motor_dir
enable_pin: !indxmcu:motor_enable
microsteps: 32
rotation_distance: 5.7  # Pre-calibrated for the DX extruder — do not change

[tmc2240 extruder]
cs_pin: indxmcu:motor_cs
spi_software_sclk_pin: indxmcu:motor_sclk
spi_software_mosi_pin: indxmcu:motor_mosi
spi_software_miso_pin: indxmcu:motor_miso
rref: 24000  # Reference resistor value for the TMC2240 on the INDX PCB — do not change
run_current: 0.6

[fan]
pin: indxmcu:part_cooling
tachometer_pin: indxmcu:part_cooling_tacho

[neopixel indx]
pin: indxmcu:led
chain_count: 16  # Fixed for the Smart Head LED array — do not change

[gcode_button endstop]
pin: ^indxmcu:endstop
press_gcode: {action_respond_info("press")}
release_gcode: {action_respond_info("release")}

[lis2dw]
# Built-in accelerometer on the INDX PCB — used for input shaper calibration
i2c_mcu: indxmcu
i2c_bus: sercom3

[angle indx]
# Magnetic encoder that reads extruder rotation — used for precise extrusion monitoring
sensor_type: as5047d
stepper: extruder
cs_pin: indxmcu:encoder_cs
spi_bus: sercom1
```

> ⚠️ **Do not change `rotation_distance`**
>
> The `rotation_distance: 5.7` value is pre-calibrated for the DX extruder and is used by the INDX tool-change macros to calculate precise filament moves during tool changes. Changing it, even slightly, will cause incorrect filament positioning and failed tool changes. Do not treat it as a value to tune. If your extrusion multiplier needs adjusting, do it in the slicer, not here.

**Finding your serial path**

The `serial` value under `[mcu indxmcu]` is unique to your board. To find it, SSH into your printer (see [Connect to your printer via SSH](#connect-to-your-printer-via-ssh)) and run:

```bash
ls /dev/serial/by-id/
```

Copy the path that starts with `usb-Bondtech_INDX` and paste it into your config.

**Configuring multiple tools**

The `[extruder]` block above is always required and represents the Smart Head's single DX extruder. INDX passive tools are **not** separate Klipper extruders — there is only ever one `[extruder]`. Additional tools (T1, T2, …) are defined in `indx.cfg`: set `variable_tool_count` and add a `variable_t{n}_x` / `variable_t{n}_dock_y` pair per tool in the `[gcode_macro TOOL_POSITIONS]` section (see [INDX macro files](#indx-macro-files)). Per-tool XY/Z offsets come from [Tool Offsets](#tool-offsets) calibration, and per-tool nozzle sizes and temperatures are set in your slicer.

##### INDX macro files

The INDX firmware plugin provides a set of `.cfg` files you include from `printer.cfg`. Each file has a specific role:

| File | Role |
| ---- | ---- |
| `indx.cfg` | User configuration: tool positions and related settings. **The only file you need to edit.** |
| `indx-tc-macros.cfg` | Tool change logic: `CHANGE_TOOL`, `PARK_TOOL`, boot detection. Do not edit. |
| `indx-cal.cfg` | Calibration macros: dock position, XY/Z offset calibration. |
| `homing.cfg` | `[homing_override]`: Y then X, ensure a tool (T0 when possible), then Z. |
| `indx-helpers.cfg` | Optional helpers: latch lock/unlock, load-cell tool presence, RESUME wrapper for mid-print detect. Include after `indx-tc-macros.cfg`. |

Include them from your `printer.cfg`:

```ini
[include indx/indx.cfg]
[include indx/indx-tc-macros.cfg]
[include indx/indx-cal.cfg]
[include indx/homing.cfg]
[include indx/indx-helpers.cfg]   # after tc-macros; after mainsail.cfg in printer.cfg
```

Klipper allows only one `[homing_override]`. If your printer already has one (sensorless current, bed raiser, etc.), merge the INDX sequence into yours instead of including `homing.cfg` as-is.

##### Mainsail RESUME coexistence

If you use Mainsail's stock `mainsail.cfg`, it defines `[gcode_macro RESUME]`. Klipper merges duplicate section names; when `indx-helpers.cfg` is included later, INDX's RESUME (tool-detect recheck) replaces Mainsail's body. Without a printer-side patch, Mainsail's temp restore, runout gate, and `_CLIENT_EXTRUDE` never run.

INDX owns the `RESUME` command and `rename_existing: RESUME_BASE`. Move Mainsail's wrapper to `_CLIENT_RESUME` in your local `mainsail.cfg` (or a small override file included after Mainsail):

1. Rename `[gcode_macro RESUME]` to `[gcode_macro _CLIENT_RESUME]`
2. Remove `rename_existing: RESUME_BASE` from that section (INDX already renames the builtin)
3. In `CANCEL_PRINT`, change `printer['gcode_macro RESUME']` to `printer['gcode_macro _CLIENT_RESUME']`
4. In `CANCEL_PRINT`, `PAUSE`, and the renamed section body, change every `SET_GCODE_VARIABLE MACRO=RESUME` to `MACRO=_CLIENT_RESUME`
5. Keep `RESUME_BASE VELOCITY=...` at the end of `_CLIENT_RESUME`

Call chain after the patch: `RESUME` (INDX) -> optional `_RESUME_PRESENCE_*` on tool-detect fail -> `_CLIENT_RESUME` (Mainsail) -> `RESUME_BASE` (Klipper). If `_CLIENT_RESUME` is missing, INDX falls back to `RESUME_BASE` so resume still works.

After editing, run `FIRMWARE_RESTART`. `HELP` should show INDX's RESUME description.

##### Automated dock X measurement (built in)

Automated dock X measurement is **built into the INDX plugin** — there is no separate Python extra to install. The plugin registers `INDX_DOCK_MEASURE`, which energises the XY motors, homes Y then X from the dock, and derives the absolute dock position from the raw stepper counts (so it works for each tool in turn without a prior `G28`).

The `indx-cal.cfg` macros wrap this into the calibration commands you actually run:

| Command | Description |
| --- | --- |
| `CALIBRATE_DOCK_X TOOL=N` | Measures dock X for tool N via `INDX_DOCK_MEASURE` and reports the value to paste into `indx.cfg`; see [Dock Position Calibration](#dock-position-calibration) |
| `READ_DOCK_POSITION TOOL=N` | Reports the current (already-homed) X as dock X for tool N |

---

##### Homing order (important)

With a dock mounted on your printer, the default homing sequence can cause crashes. The Smart Head must move away from the dock before X is homed, and Z homing needs a seated tool (the load cell is the nozzle probe).

The INDX macro package includes a ready-to-use `[homing_override]` in `homing.cfg` that handles all of this. Its sequence, in full:

1. If Z is already known: raise to `probe_z_clearance` (set in `indx.cfg`)
2. Home Y, then move to `clearance_y` so X does not sweep into the dock
3. Home X
4. Before Z: require a seated tool (`VERIFY_TOOL_PRESENT`). If a tool is already locked, Z homes with that tool (its XY/Z offsets are re-applied before the probe). If the head is empty and the dock is usable, pick T0. If Z has never been homed, dock pickup is unsafe - seat and lock a tool by hand after load-cell calibration, then home. Empty-head Z without a known tool is refused (the load cell will not trigger without a nozzle).
5. Move to the probe XY (`probe_x` / `probe_y`, or bed centre) and home Z

`CAL_Z` still stores per-tool Z offsets relative to T0. Homing no longer requires T0 when another tool is already locked - toolchanges keep applying `tool_z + global_z`, so nozzle height stays consistent after a non-T0 Z home. Mesh or tilt after that home (as in `PRINT_START`) keeps the frame consistent.

If you use sensorless XY homing, wrap the `G28 Y` / `G28 X` steps in your usual TMC current reduce/restore (merge into the override if you already have one).

**Review your `PRINT_START` macro**

If you are migrating from a single-toolhead printer, your existing `PRINT_START` macro almost certainly heats the hotend before printing starts, something like `M104 S{first_layer_temperature}` or `M109 S{first_layer_temperature}`. With INDX, this will cause problems: there is no hotend to heat until a tool has been picked up by the Smart Head.

> ⚠️ Any hotend heating commands in your `PRINT_START` macro must come **after** the first tool pick-up. Sending a heat command before a tool is picked up will result in an error, and depending on your macro structure, may cause a crash or leave the printer in a bad state.

Review your `PRINT_START` macro and move all `M104`/`M109` (and any temperature wait commands) to after the first tool pick (`Tn` / `CHANGE_TOOL`). If you are writing a fresh macro, pick up a tool first, then heat.

#### RRF (RepRapFirmware)

Configure the Bondtech INDX PCB in RRF following the [Duet INDX Toolboard documentation](https://docs.duet3d.com/en/Duet3D_hardware/Duet_3_family/INDX_Toolboard).

### Initial Startup

Before calibrating the dock or running any tool changes, verify that the Smart Head is communicating correctly and all connected components are working. Work through these checks in order before moving anything near the dock.

### 1. Verify MCU connection

Power on your printer and open Klipper (Mainsail or Fluidd). Check the MCU status in the interface; `indxmcu` should appear as connected.

If Klipper reports a timeout or cannot connect to `indxmcu`, the most common causes are:

- **Firmware not flashed**: the most likely cause on a first startup. If you haven't flashed the Bondtech INDX PCB yet, or the flash didn't complete successfully, go back to [Flash the Bondtech INDX PCB](#4-flash-the-bondtech-indx-pcb) before continuing
- **Incorrect `serial` path**: re-run `ls /dev/serial/by-id/` via SSH and confirm the path matches what's in `[mcu indxmcu]` in your config
- **Communication mode switch** not set correctly: confirm the switch on the INDX MCU PCB is set to CAN or USB to match your wiring. See [Switch configuration](#3-wiring) for reference images
- **INDX Link Cable** not fully seated at either end

Once `indxmcu` shows as connected, proceed.

### 2. Check extruder motor direction

With no filament loaded, issue a small extrude command from the Klipper console:

```gcode
G91           ; relative mode
G1 E10 F300   ; extrude 10mm
G90           ; back to absolute
```

> **Note:** If Klipper throws a "Cannot extrude — minimum extrude temperature" error, either heat the nozzle first (`M104 S200` and wait for it to reach temperature), or — on Kalico — allow cold extrusion at runtime with `M302 P1`. Run `M302 P0` to re-enable the protection once you've confirmed motor direction. No config change or restart is needed.

The extruder gear should turn in the direction that feeds filament through the tool. If it moves the wrong way, add `!` to the `dir_pin` in your `[extruder]` config and restart Klipper.

### 3. Check part cooling fan

If you have a part cooling fan connected to the Bondtech INDX PCB, trigger it from the console and confirm it spins:

```gcode
M106 S255   ; fan full speed
M107        ; fan off
```

Skip this step if you haven't connected a fan yet.

### 4. Verify accelerometer

The Bondtech INDX PCB has a built-in accelerometer; no external ADXL345 or similar sensor needed. Confirm it is responding:

```gcode
ACCELEROMETER_QUERY
```

You should see a stream of X/Y/Z acceleration values returned in the console. If you get an error, check the `[lis2dw]` section in your config for correct `i2c_mcu` and `i2c_bus` values.

### 4a. Run input shaper calibration (optional but recommended)

With the built-in accelerometer confirmed working, you can run Klipper's resonance testing to calibrate input shaper, with no external ADXL345 needed.

**Install the required Python dependencies**

These are not installed by default on most Klipper hosts. Run this once on your Pi:

```bash
sudo apt install python3-numpy python3-matplotlib libatlas-base-dev libopenblas-dev -y
~/klippy-env/bin/pip install numpy matplotlib --upgrade
```

Then restart Klipper:

```bash
sudo systemctl restart klipper
```

**Add the resonance tester config**

Make sure your config includes a `[resonance_tester]` section referencing the built-in accelerometer and a probe point near the centre of your bed:

```ini
[resonance_tester]
accel_chip: lis2dw
probe_points:
    <X_CENTER>, <Y_CENTER>, 20    # replace with your bed centre coordinates
```

> ⚠️ The built-in accelerometer on the INDX PCB is a **LIS2DW**, not an ADXL345. Use `accel_chip: lis2dw`, not `adxl345`.

**Run the tests**

Home the printer, then run one axis at a time from the Klipper console:

```gcode
TEST_RESONANCES AXIS=X
TEST_RESONANCES AXIS=Y
```

Klipper will move the toolhead through a frequency sweep and generate resonance data. Once both axes are done, run:

```gcode
SHAPER_CALIBRATE
```

This analyses the data and recommends input shaper settings. Apply the suggested values to your `[input_shaper]` section in your config, then save and restart Klipper.

> 💡 If `TEST_RESONANCES` returns an error about missing modules, the Python dependencies above were not installed correctly. Re-run the `apt install` and `pip install` commands and restart Klipper again.

### 5. First heat-up & heater calibration

The induction heater itself is controlled by a simple **on/off (watermark) loop**, which suits induction's very fast thermal response. Separately, the INDX board builds a **thermal model** of the nozzle and tool that it uses purely for **safety monitoring** — detecting a nozzle that isn't heating as expected, a tool pulled mid-heat, or a thermal runaway (these surface as the `ErrorTempDiff` / `ErrorHeatMax` conditions). The thermal model does not drive heating; it only supervises it. Before first use this model has to be calibrated. It is a one-time procedure per tool/cooling setup; the results are written to your config with `SAVE_CONFIG`.

> ⚠️ The nozzle gets hot during calibration. Pick up a tool first (`T0`) so a nozzle is present in the coil, and keep flammable material away from the Smart Head.

Run the commands in order from the Kalico/Klipper console:

| Command | What it does |
| --- | --- |
| `INDX_CALIBRATE` | Heats the nozzle through a controlled ramp and fits the thermal-model parameters (`max_power`, `thermal_capacity`, `to_ambient_r`) |
| `INDX_FAN_CALIBRATE` | Steps the part cooling fan through several speeds and models its cooling effect on the nozzle |
| `INDX_LOAD_FILAMENT` | Loads filament and measures its heat capacity so the model accounts for the energy the filament carries away (see below) |
| `SAVE_CONFIG` | Writes the calibrated values into your `[indx]` config section and restarts |

`INDX_CALIBRATE` and `INDX_FAN_CALIBRATE` characterise the nozzle/tool and the part cooling fan — run them once per tool type and cooling setup. Because these values feed the safety model rather than the control loop, don't hand-edit them afterwards; re-run the routine if the tool type or part cooling setup changes.

**Filament heat capacity.** Different filaments carry heat away from the nozzle at different rates, so the safety model also needs to know which filament is loaded. You set this when you load filament into a tool, not during the one-time calibration above:

- **Measure it** — `INDX_LOAD_FILAMENT` feeds and primes filament while measuring the actual heat capacity, then (with `APPLY=1`) writes it to your config. Most accurate; run `SAVE_CONFIG` to keep it.
- **Set it by type** — `INDX_SET_MODEL_PARAMS FILAMENT_DENSITY=… FILAMENT_HEAT_CAPACITY=…` applies known values for a material without measuring.

The `LOAD_FILAMENT` macro wraps both of these together with tool selection — see [Loading Filament into Tools](#loading-filament-into-tools).

---

**Part 3: Configuration**

---

## Configuration

### Load cell calibration

The Smart Head's load cell senses tool/nozzle touch and is the printer's **Z probe**, so it must be calibrated before the printer can home Z.

> ⚠️ **Do this before your first Z homing.** Z homing probes the bed with the load cell, so the load cell must be calibrated before a full `G28` — and therefore before dock and [Z-offset](#z-offset-calibration) calibration. It's a first-boot, by-hand step: **X and Y are homed first** (they don't use the load cell), but the tool is seated by hand because the dock can't be reached until Z is homed.

Start with **no tool on the Smart Head** and run:

```gcode
CALIBRATE_LOAD_CELL
```

This homes X and Y, opens the latch, and tares the empty head. Now **seat a passive tool on the Smart Head by hand** — the tool **must be empty** (no filament in the extruder gears) — then lock it and calibrate against the known locking force (default 1600 g):

```gcode
CALIBRATE_LOAD_CELL_APPLY GRAMS=1600
SAVE_CONFIG
```

Prefer the console? Run `LOAD_CELL_CALIBRATE`, then `TARE` with no tool, seat an **empty** tool and lock the latch, then `CALIBRATE GRAMS=1600`, `ACCEPT`, and `SAVE_CONFIG`.

Restart, then home the printer (`G28`) — Z now probes with the load cell.

### Dock Position Calibration

Before any tool changes can happen, you need to find and save the exact dock position for each tool. Two coordinates are required per tool, both set in `indx.cfg`:

> 💡 **Dock calibration tool:** A printable jig ([`INDX_Dock_calibration_tool.stl`](CAD/STL/INDX_Dock_calibration_tool.stl)) is available to help align the dock during this process. Print it before starting.

| Variable | Meaning |
| --- | --- |
| `variable_t{n}_x` | X coordinate of the tool holder centre (mm) |
| `variable_t{n}_dock_y` | Y coordinate where the tool is fully seated (mm) |
| `variable_dock_dir` | Y sign into the dock: `-1` front (min Y), `+1` rear (max Y). Default `-1`. |

The trigger line (`dock_y - dock_dir * trigger_offset`) is derived automatically; you only set `dock_y`.

For a rear dock, set `variable_dock_dir: 1` and put `clearance_y` on the bed side of the tools.

> ⚠️ **Take this slow.** Moving the Smart Head into the dock area without verified coordinates is one of the most crash-prone steps in the entire INDX setup. A misaligned approach at speed can damage the Smart Head, the passive tools, or the dock itself.
>
> - **Always use the smallest jog increments available** (0.1 mm or less) when approaching a tool
> - **Never jog in Y toward the dock** until you are confident the X position is correct
> - **Keep your hand near the emergency stop** (or have it open in your browser) throughout this process
> - If anything looks wrong, stop immediately and re-evaluate before continuing

---

#### Finding dock_y (Y: fully seated position)

With the Smart Head holding the tool, carefully jog in Y in small increments until the tool is fully seated in the dock. When it feels fully engaged, run:

```gcode
CAL_SET_DOCK_Y
```

The console will report the current Y as `dock_y` for that tool. Paste the reported value into `indx.cfg`:

```ini
variable_t0_dock_y: -26.0   # from CAL_SET_DOCK_Y output
```

Repeat for each tool and restart Klipper to apply.

---

#### Finding dock_x (X: tool centre)

Three options; choose one:

**Option A: `CALIBRATE_DOCK_X` (automated, built in)**

Measures the absolute X position without needing a prior home, using the plugin's native `INDX_DOCK_MEASURE` (which derives the dock position from the raw stepper counts across the Y+X homing sequence).

1. `M84` (disable motors)
2. Manually slide the toolhead to the T0 dock
3. Run:
   ```gcode
   CALIBRATE_DOCK_X TOOL=0
   ```
   The macro homes Y then X and reports the measured `dock_x` for that tool. Paste it into `indx.cfg`:
   ```ini
   variable_t0_x: 0.000   # from CALIBRATE_DOCK_X output
   ```
4. For each additional tool: `M84`, slide to the dock, run `CALIBRATE_DOCK_X TOOL=N`. No `FIRMWARE_RESTART` needed between tools.
5. Once all tools are recorded, `RESTART` to apply, then `G28` to restore normal machine coordinates.

**Option B: `READ_DOCK_POSITION` (if already homed)**

If the printer is already homed, jog the Smart Head to the tool's dock X position in Mainsail or Fluidd and run:

```gcode
READ_DOCK_POSITION TOOL=0
```

Reports the current X as `dock_x` for that tool. Paste the value into `indx.cfg` (`variable_t{n}_x`) and `RESTART` to apply.

**Option C: manual**

Home the printer, jog the Smart Head to the dock X for each tool, and note the X coordinate shown in the interface. Enter it as `variable_t{n}_x` in `indx.cfg`.

> 💡 **Home regularly.** Stepper motors can lose steps if a crash or hard stop occurs, meaning the position shown in your interface may no longer match the actual toolhead position. Re-home your printer (`G28`) before recording any coordinates, and again after any crash or unexpected movement. If you suspect steps have been lost, discard any coordinates taken since the last home and start that tool's calibration over.

#### First tool change test

Once you have calibrated the dock position for at least one tool, do a controlled first pick-up to confirm it works before setting up the full multi-tool configuration.

> ⚠️ **Take this slow.** Use the smallest jog increments and keep your hand near the emergency stop throughout. If anything looks wrong, stop immediately.

1. Home the printer (`G28`)
2. Pick up the tool:
   ```gcode
   T0
   ```
3. Confirm the Smart Head locks onto the tool and the nozzle begins heating
4. Once at temperature, confirm the DX extruder can feed filament (optional: extrude a short amount manually)
5. Park the tool back in the dock:
   ```gcode
   PARK_TOOL
   ```
6. Confirm the tool deposits cleanly and the Smart Head returns to a safe position

If the pick-up or deposit fails, do not retry at speed. Go back to the dock position calibration steps above and recheck the coordinates for that tool.

---

### Tool Offsets

Each passive tool has a slightly different position relative to the Smart Head pickup point. Tool offsets must be calibrated so prints align correctly when switching tools. There are several ways to do this, ranging from free manual methods to precise hardware-assisted ones.

---

### Method 1: Print and adjust (free, no extra hardware)

The simplest approach: print a multi-tool test pattern, measure any misalignment visually or with calipers, and adjust offsets in your config manually. Repeat until aligned.

This is the lowest-cost method but also the least precise and most time-consuming. It's a good starting point if you have no other hardware available. A well-regarded starting point is the [Offset XY Dual Extruder / IDEX Calibration print](https://www.printables.com/model/129617-offset-xy-dual-extruder-idex-calibration); print it with two tools, measure any X/Y misalignment with calipers, update the offsets in your config, and reprint until they align.

Because the test print uses two tools at a time, always use T0 as your reference tool and calibrate each additional tool against it separately: first print T0 + T1, then T0 + T2, then T0 + T3, and so on. Do not try to calibrate T1 against T2 directly; everything should be referenced back to T0.

**Precision:** Low–medium | **Cost:** Free

---

### Method 2: Nudge (automatic, requires small hardware)

[Nudge](https://github.com/zruncho3d/nudge) is a low-cost contact probe that automates X/Y/Z nozzle alignment. The nozzle physically touches the probe from multiple directions; software calculates exact offsets for each tool automatically.

Nudge is highly repeatable, typically below 0.003mm standard deviation over 10 samples, and can be permanently mounted inside a heated chamber. It's a popular choice in the tool changer community.

**Precision:** High | **Cost:** Low (probe hardware + printed parts)

---

### Method 3: Nozzle camera (most precise XY, higher cost)

A nozzle-mounted or fixed camera system (e.g. [Axiscope](https://github.com/nic335/Axiscope)) lets you visually align tools with sub-micron precision. Offsets are derived from image analysis rather than physical contact.

The INDX macro package includes a built-in camera calibration workflow (`CAL_01` → `CAL_02` → `CAL_03`) that automates the offset calculation once a camera is set up.

**Workflow:**

1. Pick up T0 and jog the nozzle tip to the centre of your camera crosshair. Run:
   ```gcode
   CAL_01_SET_CAMERA_REF
   ```
   This saves the current position as the reference point.

2. For each additional tool, run:
   ```gcode
   CAL_02_PREP_TOOL_CAL TOOL=1
   ```
   The macro picks up the tool and moves it to the camera position. Re-centre the nozzle in the crosshair using the jog controls, then run:
   ```gcode
   CAL_03_SAVE_XY_OFFSET
   ```
   The offset is calculated and saved automatically. Repeat for every additional tool.

Offsets are saved as `t{n}_offset_x` / `t{n}_offset_y` and applied immediately on the next tool pick-up.

**Precision:** Very high | **Cost:** Medium–high (camera hardware)

---

### Z offset calibration

Regardless of which XY method you use, Z offsets are set automatically using the load cell.

#### Z auto-calibration: CAL_Z

`CAL_Z` probes every tool with the load cell and sets all Z offsets in one automated run. T0's probe result establishes the global Z offset.

```gcode
CAL_Z
```

Prerequisites:
- Printer homed (homes automatically if not)
- **No filament available to the extruder gears in any tool** — latch engage moves during pickup can spike load-cell readings and calibration to fail if filament is loaded.

Per tool, the macro:
1. Picks up the tool
2. Pre-probes 3× at a per-tool debris-clearing spot to clean the nozzle tip
3. Runs a convergence loop at a clean spot: probes repeatedly until the 4-sample rolling variance is below 0.005 mm, fuzzing to a new position if it stalls
4. Takes a median of 5 final samples as the result
5. Parks the tool

T0's median result sets the global Z reference. All other tools' offsets are saved as `t{n}_offset_z` relative to T0. Run `CAL_CHECK_OFFSETS` to inspect the results.

---

### Recommended approach

| Need | Recommended method |
| ---- | --- |
| Z offset only | `CAL_Z` |
| XY + Z, no extra hardware | Method 1 (print and adjust) or Method 2 (Nudge) for XY + `CAL_Z` for Z |
| Maximum XY precision | Method 3 (camera) for XY + `CAL_Z` for Z |

### Temperature & Induction Settings

Temperature is set in your slicer, the same way you would set it for any standard hotend: assign a target temperature to each filament or color in your project. INDX behaves like a normal hotend from the slicer's perspective.

The main difference from a traditional hotend is heat-up speed. A conventional heater block takes 30–60 seconds to reach printing temperature. With induction heating acting directly on the nozzle with very low thermal mass, INDX does it in around 4 seconds. That's what makes ~14-second tool changes possible.

**No induction-specific settings are required.** The induction board handles heating automatically. There are no power or frequency parameters to configure.

**Preheating is not supported and not possible.** Passive tools contain no electronics; there is nothing to preheat while a tool is parked in the dock. Do not configure standby or preheat temperatures for individual tools in your slicer; doing so may produce errors since the firmware has no way to act on them for a docked tool.

### Speed & Acceleration

Tool change motion speed and acceleration are controlled by three preset modes: **Stealth**, **Normal**, and **Sport**. Each mode sets a multiplier that is applied against the `max_velocity` and `max_accel` values defined in your `printer.cfg`. The macros read those limits at runtime, so the modes automatically scale to whatever printer they're running on, with no hardcoded numbers.

| Mode | G-code | Speed multiplier | Accel multiplier | XY stepper mode |
|---|---|---|---|---|
| **Stealth** | `MODE_STEALTH` | 20% | 20% | StealthChop (quiet) |
| **Normal** | `MODE_NORMAL` | 70% | 70% | SpreadCycle |
| **Sport** | `MODE_SPORT` | 100% | 100% | SpreadCycle |

**Stealth** runs the toolchange at 20% of your printer's configured limits. The XY steppers are switched to StealthChop, making the swap nearly silent. Useful for overnight printing or noise-sensitive environments. The trade-off is a longer toolchange duration and slightly higher stepper heat.

**Normal** is the default. It uses 70% of your printer's limits with SpreadCycle, a good balance of speed, noise, and reliability for most printers and materials.

**Sport** uses the full `max_velocity` and `max_accel` from your `printer.cfg`. This gives the fastest possible toolchange times for your specific printer. Make sure your configured limits are within what your printer can actually handle; if `max_velocity` or `max_accel` are set too high, Sport mode will expose that immediately. Input shaper should be tuned before running Sport; without it, high-acceleration toolchange moves can cause the steppers to lose steps.

Mode switching also sets StealthChop or SpreadCycle on every configured XY TMC driver (`tmc2208`, `tmc2209`, `tmc2130`, `tmc2240`, or `tmc5160`). On AWD setups, that includes `stepper_x1` and `stepper_y1` when present. The driver type is detected once at boot from your `printer.cfg`.

The active mode persists across reboots. To change it, run the macro from the console or add it to your start G-code:

```gcode
MODE_STEALTH   ; quiet/slow
MODE_NORMAL    ; default
MODE_SPORT     ; full speed
```

> **Note:** The speed limits are applied only during toolchange motion. As soon as the swap completes, the macros restore whatever velocity and acceleration limits the slicer set before the toolchange, and your print resumes at its normal print speeds.

---

**Part 4: Day-to-day Use**

---

## Using INDX

### Loading Filament into Tools

Filament can be loaded into a passive tool in three ways; try each and use what works best for your setup:

- **While the tool is in the dock**: convenient if the dock is easily accessible
- **While the tool is picked up by the Smart Head**: useful if the toolhead position is easier to reach
- **Before placing the tool in the dock**: load it on the bench, then dock it

There is no single correct method. Your printer geometry, spool placement, and personal preference will determine what works best.

**Guided loading with `LOAD_FILAMENT`**

The `LOAD_FILAMENT` macro handles the whole sequence for you: it picks up the tool, tells the safety thermal model which filament is loaded, heats to temperature, then feeds and primes.

```gcode
LOAD_FILAMENT TOOL=0 TYPE=PLA
```

- **`TOOL=<n>`** — which tool to load (it is picked up automatically).
- **`TYPE=<material>`** — applies a density + heat-capacity preset and a default load temperature. Built-in types: `PLA`, `PETG`, `ABS`, `ASA`, `PA`, `PC`, `TPU`. Edit the `filament_presets` table in `indx-cal.cfg` to add materials or tune values. Presets may also set an optional `speed` (mm/s) for the feed/prime step; `TPU` uses 2 mm/s so soft filament does not buckle during guided load.
- **`TEMP=<°C>`** *(optional)* — override the preset load temperature.
- **`MEASURE=1`** *(optional)* — measure this filament's actual heat capacity while loading instead of using the preset (most accurate). Run `SAVE_CONFIG` afterwards to keep it.

`LOAD_FILAMENT` needs a calibrated thermal model — run `INDX_CALIBRATE` first (see [First heat-up & heater calibration](#5-first-heat-up--heater-calibration)). The manual methods below work too; if you load by hand, set the filament's heat capacity separately so the safety model stays accurate.

**Filament path**

How filament is routed from the spool to the tool depends entirely on your printer. Common approaches include Bowden tubes from a spool holder to the dock, or direct-feeding from a nearby spool. There are no INDX-specific constraints on tube length for standard materials; route it in whatever way suits your printer.

**PTFE tube management**

With four or more tools, PTFE tube management becomes important. Loose, unrestrained tubes will move during printing and can knock into each other or into docked tools, potentially dislodging a tool from the dock mid-print, which can cause serious damage to the Smart Head, the tool, or the dock itself.

Two approaches work well:

- **Clip the tubes together**: bundle the PTFE tubes and clip them at intervals so they move as a single unit rather than independently
- **Mount the tubes rigidly along the top interior of the printer**: routing and securing the tubes along the frame keeps them stable and out of the motion path entirely. When doing this, make sure the tubes are long enough to reach all corners of the build area without pulling on the toolhead; a tube that is too short will create tension on the Smart Head as it moves, which can affect print quality or cause tool change failures

Either approach significantly reduces the risk of tubes interfering with docked tools. If you are running four or more tools, do not leave PTFE tubes unmanaged.

**Flexible filaments (TPU and similar)**

Keep the filament path as short as possible. Long Bowden paths cause flex filament to buckle rather than feed. Where possible, feed directly into the tool without a Bowden tube, or use a very short, straight tube. Avoid sharp bends in the path. `LOAD_FILAMENT TYPE=TPU` also feeds slower than other presets (2 mm/s); tune `speed` in `filament_presets` if needed.

### Performing Tool Changes

Tool changes happen automatically when triggered by your slicer's multi-material G-code. The Klipper plugin provides standard `T0`, `T1`, `T2` (etc.) macros for selecting any tool, the same commands your slicer will output.

You can also trigger a manual tool change directly from the Klipper console or a macro:

```gcode
T0  ; pick up tool 0
T1  ; pick up tool 1
T2  ; pick up tool 2
```

> ⚠️ **Never remove a tool while the nozzle is heating.** If a tool is physically removed from the Smart Head while the induction coil is active, the firmware on the Bondtech INDX PCB will crash. You will need to run `FIRMWARE_RESTART` in the Klipper console before the printer can be used again.

**Priming before a print**

It is recommended to prime each nozzle before starting a print. Priming builds pressure in the nozzle and purges any filament that has been sitting idle and may have degraded or partially retracted. How you do this is up to you; common approaches include:

- A purge line in your slicer's print start G-code
- A prime routine in your `PRINT_START` macro
- A dedicated prime tower at the start of the print

The specifics depend on your slicer and macro setup. Check what other tool changer users in the community are doing for inspiration.

### Slicer Setup

Any slicer that supports **multiple filaments or colors** works with INDX; slicer compatibility is not INDX-specific. If your slicer can output multi-tool G-code (`T0`, `T1`, `T2`…), INDX can execute it.

Common slicers used with INDX include PrusaSlicer, OrcaSlicer, SuperSlicer, and Cura. Refer to your slicer's documentation for how to configure multiple extruders/tools.

**INDX-specific slicer settings to be aware of:**

- **Wipe tower:** A wipe tower is recommended for best results but not strictly required. Because INDX produces near-zero ooze by design, the wipe tower can be kept small compared to filament-switcher systems. You can experiment with disabling it for single-material-per-layer prints, but use it when printing materials prone to stringing.
- **Tool change G-code:** A small custom G-code snippet is required in your slicer's tool change script. The snippet and where to add it differs per slicer:

  **OrcaSlicer**

  Add under Printer Settings → Machine G-code → Tool change G-code:
  ```gcode
  T{next_extruder}
  M400
  ```

  **PrusaSlicer / SuperSlicer**

  1. Under Printer Settings → General → Capabilities, set **Number of extruders** to match your tool count
  2. Make sure **Single Extruder Multimaterial Printer** is **unchecked**; this mode is for filament switchers (MMU/AMS) and must be off for a tool changer
  3. Under Printer Settings → Custom G-code → Tool change G-code, add:
  ```gcode
  T{next_extruder}
  {if (wipe_tower)}
  G0 Y{wipe_tower_y+2} X{wipe_tower_x+2} F{travel_speed*60}
  G0 Z{layer_z} F{travel_speed*60}
  {endif}
  M104 S{temperature[next_extruder]}
  TEMPERATURE_WAIT SENSOR=extruder MINIMUM={temperature[next_extruder]-5} MAXIMUM={temperature[next_extruder]+5}
  ```

  This selects the next tool, moves to the wipe tower (if one is enabled) so the new (initially cold) tool heats and purges there, then sets the new tool's temperature and waits for the induction coil to bring it up to temperature before printing resumes.

  **SuperSlicer** uses the same template engine and variable names as PrusaSlicer, so this snippet works unchanged in both. (PrusaSlicer's older `[...]` placeholder form also works in both if you prefer it, e.g. `M104 S[temperature[next_extruder]]`.)

  **Cura**

  > ⚠️ This configuration has not been fully verified. If you run into issues, ask on the [Bondtech Discord](https://discord.gg/XDX9jDXN6e).

  Cura handles tool changes differently from the PrusaSlicer family: it emits the `T{n}` command automatically and runs **per-extruder** start/end G-code, so there is no single "tool change G-code" field to edit. Configure it as follows:

  1. In **Settings → Printer → Manage Printers → Machine Settings**, set **Number of Extruders** to match your tool count. Cura then outputs `T0`, `T1`, … automatically at each tool change.
  2. Enable **Prime Tower** (search "prime tower" in the print settings). This is Cura's equivalent of the wipe tower; Cura moves to it and purges the freshly heated tool automatically, so you don't script the move yourself.
  3. In **Machine Settings**, open each extruder's tab and add to its **Extruder Start G-code** (this runs every time that tool becomes active):
  ```gcode
  M104 S{material_print_temperature}
  TEMPERATURE_WAIT SENSOR=extruder MINIMUM={material_print_temperature}
  ```

  > **Notes for Cura:**
  > - Cura's start/end G-code does **not** support arithmetic in placeholders (e.g. `{material_print_temperature - 5}` will not work), so use the bare target. Because an INDX tool is always cold when picked up, waiting on `MINIMUM` alone is sufficient; the nozzle only ever needs to heat *up* to temperature.
  > - Do **not** set per-extruder **Standby Temperature** values; passive tools cannot be preheated in the dock (see [Temperature & Induction Settings](#temperature--induction-settings)).
- **Slicer profiles:** Pre-made printer profiles for INDX are being developed and will be made available before release. They are not ready for general use yet.

---

**Part 5: Designing for INDX**

---

## Designing for INDX

This section is for users who want to design custom mounts, docks, or printer integrations for INDX.

### Dock Design

The dock holds passive tools in precise, repeatable positions so the Smart Head can pick them up reliably. There are strict geometry requirements; a dock that doesn't meet them will cause failed or inconsistent tool changes.

The reference dock design is available on [github.com/BondtechAB/INDX](https://github.com/BondtechAB/INDX). Use it as the starting point for any custom design.

**Key design constraints**

Each dock is approximately **70mm tall, 28.5mm wide (X), and 25mm deep (Y)**. Minimum tool center-to-center spacing is **34mm** bare, or **41mm** when using the Bondtech part cooling solutions. The design must achieve a pickup repeatability of **within 0.2mm**.

**Material recommendations**

Bondtech's sold docks use SLS-printed Nylon 12 GF. For self-printed docks, use a material that is dimensionally stable at elevated temperatures; the dock sits near the print area and will experience heat cycles. ASA or ABS are common choices. Avoid PLA.

**Community designs**

Community dock designs for specific printers and frames will be collected on [github.com/BondtechAB/INDX](https://github.com/BondtechAB/INDX). If you design a dock for an unlisted setup, submit it via pull request.

### Part Cooling

INDX's modular part cooling system is designed to be extended by the community. The cooling solution snaps onto the outside of the Smart Head cowlings; the interface geometry is defined in the cowling CAD files, which Bondtech will publish on [github.com/BondtechAB/INDX](https://github.com/BondtechAB/INDX).

If you design a custom part cooling solution using the cowling CAD files as a reference, we'd love to see it. Community-contributed cooling designs will be collected in the GitHub repository. Submit yours via pull request.

### CAD Files & Templates

All official CAD files are hosted on **Bondtech's GitHub**: [github.com/BondtechAB/INDX](https://github.com/BondtechAB/INDX)

**Reference geometry (STEP)**

The STEP file is the master reference model; it contains the geometry of every printable part listed below, so use it as the starting point for designing custom mounts, adapters, or cooling solutions.

| File | Format | Description |
| ---- | --- | --- |
| [`INDX_simplified_1.17.step`](CAD/INDX_simplified_1.17.step) | STEP | Simplified reference model of the full INDX assembly, includes all printable parts below |

**Printable parts (STL)**

These are print-ready STLs of the individual parts. They are all derived from the reference STEP above.

| File | Part | Description |
| ---- | ---- | --- |
| [`INDX_MGN12H_X-carriage.stl`](CAD/STL/INDX_MGN12H_X-carriage.stl) | X-carriage adapter | Mounts the Smart Head to MGN12H linear rails (6mm belts) |
| [`INDX_Front_cover_left.stl`](CAD/STL/INDX_Front_cover_left.stl) | Smart Head cover | Front cover, left half |
| [`INDX_Front_cover_right.stl`](CAD/STL/INDX_Front_cover_right.stl) | Smart Head cover | Front cover, right half |
| [`INDX_PCB_Cover.stl`](CAD/STL/INDX_PCB_Cover.stl) | PCB cover | Protective cover for the Bondtech INDX PCB |
| [`INDX_4010_Duct_Left.stl`](CAD/STL/INDX_4010_Duct_Left.stl) | Part cooling (4010) | Dual 40×10 blower duct, left half |
| [`INDX_4010_Duct_Right.stl`](CAD/STL/INDX_4010_Duct_Right.stl) | Part cooling (4010) | Dual 40×10 blower duct, right half |
| [`INDX_CPAP_Duct_Left.stl`](CAD/STL/INDX_CPAP_Duct_Left.stl) | Part cooling (CPAP) | CPAP duct, left half |
| [`INDX_CPAP_Duct_Right.stl`](CAD/STL/INDX_CPAP_Duct_Right.stl) | Part cooling (CPAP) | CPAP duct, right half |
| [`INDX_CPAP_Duct_Top.stl`](CAD/STL/INDX_CPAP_Duct_Top.stl) | Part cooling (CPAP) | CPAP duct, top manifold |
| [`INDX_Beacon_Cartographer_Mount.stl`](CAD/STL/INDX_Beacon_Cartographer_Mount.stl) | Probe mount | Mount for a Beacon / Cartographer scanning probe |
| [`INDX_Dock_calibration_tool.stl`](CAD/STL/INDX_Dock_calibration_tool.stl) | Dock calibration tool | Printed jig for calibrating dock position during initial setup; see [Dock Position Calibration](#dock-position-calibration) |

The repository is licensed under **GPL-3.0**.

More files (dock templates, additional X-carriage adapters, tool body templates) will be added as the project develops. Community contributions are welcome via pull request.

---

**Part 6: Maintenance, Support & Community**

---

## Maintenance

The Smart Head's mechanism is designed to run for a long time with minimal upkeep, but a periodic inspection keeps tool changes reliable and prevents wear from going unnoticed.

**How often:** Perform this inspection every **500,000 tool cycles**. More frequent checks can be beneficial. If you don't change tools often, inspect roughly every **1,000 print hours** instead.

Work through the following checks:

- **Check for play in the opening mechanism and drive gear assembly.** There should be no slop anywhere. Feel the nozzle lever assembly pin to confirm there is no play in the opening mechanism or in the drive gear assembly.
- **Check the activator moves freely.** With the extruder fully closed, the activator should be able to be pushed slightly up and down easily, without sticking or catching.
- **Check the magnet activator assembly.** It should move completely friction-free, with no resistance.
- **Inspect the coil for nozzle contact.** Check that misaligned (crooked) nozzles have not struck the coil. The coil area should be free of any marks left by a nozzle.
- **Inspect the gears.** Check that the drive gear assembly is not damaged and that the gears are not worn.
- **Grease the gear teeth.** Apply fresh grease to the drive gear teeth and the motor gear teeth.

### Nozzle clog: cold pull procedure

A cold pull clears carbonized plastic, debris, and partial or full clogs from the nozzle. It is the most effective way to restore a blocked or under-performing tool.

**What you need:** Standard PLA filament. Use a light color so you can inspect the extracted debris.

**Steps:**

1. **Park the tool and disconnect the PTFE tube.** Park the target tool. With the Smart Head receiver open, remove the tool from the dock and disconnect the PTFE tube from the top of the tool. Check that no loose filament or debris remains in the upper guide channel.

2. **Seat the tool in the Smart Head.** Manually insert the tool into the Smart Head, keeping the receiver open throughout the entire procedure.

3. **High-temperature flush.** Set the nozzle temperature to **250–280°C**. Once at temperature, feed PLA manually down into the tool and push until ~30mm extrudes from the nozzle tip. This fills the melt zone and integrates any old residue into the new PLA plug.

4. **Cool and pack.** Drop the temperature setpoint to **120°C**. While the tool cools, maintain steady downward pressure on the filament. This counteracts shrinkage and ensures the PLA packs tightly into the nozzle geometry.

5. **Pull.** When the temperature reaches 120°C, press the tool body firmly down into the Smart Head with one hand to hold it in place. With the other hand, pull the filament slowly and steadily upward. Increase force gradually until the plug releases from the nozzle walls and slides out. Pulling too fast will snap the filament before the plug clears.

6. **Smooth withdrawal.** Once the plug releases, maintain a steady, continuous upward motion until the entire PLA strand is fully extracted from the tool.

**Verify the result.** Inspect the tip of the extracted plug. On a CHT tool, a successful pull shows **three separate thin strands** at the tip — the negative impression of the CHT internal geometry. A blunt or broken tip means the plug didn't release cleanly; repeat the cycle.

Repeat the full cycle **2–3 times** to ensure all carbonized material and debris are fully extracted.

---

## Troubleshooting

### Tool not picking up reliably

If the Smart Head consistently fails to pick up a tool, or picks up unreliably, work through these causes in order:

**Dock position miscalibrated**

This is the most common cause. Even a small X or Y offset is enough to cause failed or inconsistent pickups. Go back to [Dock Position Calibration](#dock-position-calibration) and redo the alignment for the affected tool. Re-home the printer first (`G28`) to make sure the coordinates are accurate before recording anything.

**Lost steps from a previous crash**

If the Smart Head has crashed into the dock or a tool, the stepper motors may have lost steps. This means the position shown in your interface no longer matches the actual toolhead position; coordinates you saved before the crash may now be wrong. Re-home the printer and redo dock position calibration for any tools affected.

**Dock not mounted rigidly**

If the dock has shifted or flexes during operation, the tool positions will no longer match the calibrated coordinates. Check that the dock is firmly secured to its mounting point; no movement should be possible when you push on it. Retighten any fasteners and redo dock position calibration after.

### Nozzle not reaching temperature / overheating

The induction coil is fast and powerful; it can heat the nozzle to dangerously high temperatures quickly. If you are seeing the nozzle under-read (temperature reported lower than actual) or unexpectedly overheating, the most likely cause is that the passive tool is not fully seated or is misaligned in the Smart Head.

When the nozzle is not correctly positioned inside the coil, the IR sensor reads the temperature from a suboptimal angle, resulting in a lower reading than the actual nozzle temperature. The firmware then continues heating to compensate, causing the nozzle to overheat beyond the intended target.

> ⚠️ Do not allow paper, wiring, or other flammable material near the induction coil area. Keep firmware up to date; incorrect firmware versions may not correctly limit heating.

**If the nozzle is not reaching temperature:**
- Verify the passive tool is fully picked up and seated correctly in the Smart Head; it should click into the Maxwell coupling and show no visible misalignment
- Check that the tool has not been bent or damaged in a way that affects its position inside the coil
- Confirm the firmware is up to date

**If the nozzle is overheating:**
- Immediately cancel any print or heating command
- Inspect the tool for misalignment or damage
- Do not continue using the tool until the cause is identified

### Filament jam in passive tool

Filament jams in a passive tool are resolved the same way as any standard FDM nozzle jam:

1. Heat the nozzle to printing temperature for the material that is stuck
2. Attempt a manual retraction to pull the filament back out; if it doesn't move, heat slightly higher and try again
3. If the filament has broken inside the tool, carefully remove the tool from the dock and clear the jam from the top of the filament path using a thin wire or fresh filament to push the remnant out
4. Inspect the PTFE tube inside the tool for damage or deformation; replace it if it has been heat-damaged
5. Check the nozzle for a partial or full clog and clean or replace as needed

For persistent clogs or partial blockages that survive the steps above, use the [cold pull procedure](#nozzle-clog-cold-pull-procedure).

### DX extruder not opening or closing correctly after a crash

If the Smart Head has crashed into the dock, a tool, or part of the printer frame, the DX extruder mechanism may have been physically damaged. Symptoms include:

- The extruder no longer grips filament properly
- The extruder arm does not open or close as expected when a tool is picked up or deposited
- Inconsistent extrusion or grinding sounds during extrusion

**What to do**

Visually inspect the Smart Head for any obvious physical damage: bent parts, broken clips, or anything that looks out of position. Do not attempt to force the mechanism open or closed if it is stuck.

If hardware damage is confirmed or suspected, contact Bondtech support at [bondtech.se/contact](https://www.bondtech.se/contact/) before continuing to use the system. Running with a damaged DX extruder can cause print failures and may cause further damage.

### `indxmcu` not connecting

If Klipper reports a timeout or cannot find `indxmcu` on startup, work through these causes:

- **Firmware not flashed**: the most likely cause on a first startup. If you haven't flashed the Bondtech INDX PCB, or the flash didn't complete successfully, the board will not appear. Go back to [Flash the Bondtech INDX PCB](#4-flash-the-bondtech-indx-pcb) and redo the process.
- **Wrong `serial` path**: the path in `[mcu indxmcu]` must match exactly. SSH into your printer and run `ls /dev/serial/by-id/` to get the correct path, then update your config and restart Klipper.
- **Communication mode switch not set correctly**: check the switch on the INDX MCU PCB matches your communication mode (CAN or USB). See [Wiring](#3-wiring) for reference images.
- **INDX Link Cable not fully seated**: check both ends of the cable at the Link Board and the Bondtech INDX PCB.

**Recovery: CAN_RESET jumper**

If the board has non-functioning firmware and cannot be reached normally, you can force a firmware re-fetch using the CAN_RESET jumper on the Bondtech INDX PCB:

1. Power down the printer
2. Install the CAN_RESET jumper on the PCB
3. Power up; the bootloader will reset the CAN address to the default (121) and fetch and install new firmware, even if firmware is already present
4. Once flashing is complete, power down, remove the CAN_RESET jumper, and power up again

### Link Board not detected on Raspberry Pi 3

If you are running a **Raspberry Pi 3** and the Link Board is not being detected as a USB device, even though the cable is connected and the board is powered, you may be hitting a known kernel bug affecting USB device enumeration on the Pi 3.

**Symptom:** `ls /dev/serial/by-id/` returns nothing, or the Link Board disappears after a reboot, despite the board being powered.

**Fix:**

1. SSH into your Raspberry Pi and open the boot config file:

   ```bash
   sudo nano /boot/firmware/config.txt
   ```

2. Use the arrow keys to scroll to the very end of the file. Add the following on its own line (make sure the entire entry is on a single line with no line breaks):

   ```
   dtoverlay=dwc2
   ```

3. Save the file: press **Ctrl+O**, then press **Enter** to confirm.

4. Exit nano: press **Ctrl+X**.

5. Verify the line was added correctly before rebooting:

   ```bash
   grep "dtoverlay=dwc2" /boot/firmware/config.txt
   ```

   You should see `dtoverlay=dwc2` printed back. If nothing is returned, open the file again and repeat from step 2.

6. Reboot your Raspberry Pi:

   ```bash
   sudo reboot
   ```

After rebooting, run `ls /dev/serial/by-id/` to confirm the Link Board is now visible, then continue with Klipper configuration.

> See the upstream kernel issue for background: [raspberrypi/linux#6100](https://github.com/raspberrypi/linux/issues/6100)

### Smart Head crashes into dock on homing

If the Smart Head slams into the dock or the docked tools when you run `G28`, the most likely cause is that the homing order has not been configured. By default, Klipper homes X before Y; if the Smart Head is near the dock when homing starts, a full-speed X move can send it directly into the dock.

Add a `[homing_override]` section to your `printer.cfg` that homes Y before X. See [Homing order](#homing-order-important) for the recommended config. After any crash, re-home the printer before moving on; the stepper motors may have lost steps, making the position shown in your interface unreliable.

### Extruder feeding filament in the wrong direction

If filament moves backward (out of the nozzle) when you issue an extrude command, the motor direction is inverted. Add `!` to the `dir_pin` line in your `[extruder]` config and restart Klipper:

```ini
dir_pin: !indxmcu:motor_dir
```

Re-run the extrude check from [Initial Startup](#2-check-extruder-motor-direction) to confirm the direction is now correct.

### "Cannot extrude — minimum extrude temperature" error

Klipper prevents extrusion below a minimum temperature to protect against cold extrusion. This commonly appears during initial startup when you try to verify motor direction before the nozzle is hot.

Either heat the nozzle to printing temperature first (`M104 S200` and wait), or — on Kalico — allow cold extrusion at runtime with `M302 P1` (no config change or restart needed). Run `M302 P0` to re-enable the protection once you've confirmed motor direction.

> **Note:** Tool changes themselves are not affected by this — the latch moves during a tool change run through `INDX_EXTRUDER_MOVE`, which operates the extruder cold without touching `min_extrude_temp`. This only comes up for manual extrude/direction checks.

### Heatsink fan runs continuously on startup

The heatsink fan defaults to running continuously when the Bondtech INDX PCB has no firmware installed, or while firmware is being updated. If the fan runs non-stop and the printer cannot connect to `indxmcu`, flash the firmware; see [Flash the Bondtech INDX PCB](#4-flash-the-bondtech-indx-pcb).

### Accelerometer not responding

If `ACCELEROMETER_QUERY` returns an error, check that the `[lis2dw]` section in your config has the correct `i2c_mcu` and `i2c_bus` values:

```ini
[lis2dw]
i2c_mcu: indxmcu
i2c_bus: sercom3
```

If the values are correct and the accelerometer still doesn't respond, check that `indxmcu` itself is connected; an MCU connection issue will prevent all sensor reads.

### PTFE tube knocks a tool out of the dock mid-print

If a docked tool is being displaced during a print, loose PTFE tubes are the most likely cause. With four or more tools, unrestrained tubes move freely during toolhead motion and can knock into docked tools hard enough to dislodge them.

Bundle and clip the PTFE tubes together so they move as one unit, or route and secure them along the top interior of the printer frame. If a tool has been knocked out of the dock, cancel the print, re-seat the tool, and add tube management before continuing.

### Slicer not triggering correct tool changes

If tools are not being swapped during a print, or the slicer is generating incorrect tool change G-code, check the following:

**PrusaSlicer / SuperSlicer:** Make sure **Single Extruder Multimaterial Printer** is **unchecked** under Printer Settings → General → Capabilities. This mode is for filament switchers (MMU, AMS) and generates the wrong G-code for a tool changer. With it enabled, the slicer will not output standard `T0`, `T1`… commands.

**All slicers:** Confirm you have added the required tool change G-code snippet for your slicer. Without it, the slicer may pause or error at tool changes rather than triggering the INDX macros. See [Slicer Setup](#slicer-setup) for the correct snippet for your slicer.

---

## FAQ

**How many tools can I run simultaneously?**

For the Development Kit, there is no fixed limit; you can run as many tools as your printer has physical space for in the dock. The Prusa CORE One / CORE One L kit supports up to 8 tools, as that is the maximum that fits in the Prusa enclosure.

**Does each tool need its own filament spool?**

Yes. Each passive tool has its own direct filament feed. There is no shared filament path.

**Do I need a wipe tower?**

A wipe tower is recommended but not required. INDX produces near-zero ooze by design, so the wipe tower can be kept much smaller than with filament-switcher systems. Whether you need one depends on the materials you're printing with.

**Will it work with my [printer model]?**

If your printer is CoreXY with open firmware, it's likely compatible. Community-contributed configs and integration guides live on [github.com/BondtechAB/INDX](https://github.com/BondtechAB/INDX). If your printer isn't listed, you can contribute an integration.

**Can I mix nozzle sizes?**

Hardware-wise, yes. There is no restriction on mixing nozzle sizes across tools. Each Thin Passive Tool carries its own nozzle independently, so a setup with e.g. two 0.4mm, one 0.6mm, and one 0.8mm tool is fully valid. Whether your slicer supports assigning different nozzle diameters per extruder is a slicer question, not an INDX limitation.

Note that the **Prusa CORE One / CORE One L kit** ships with either 4 or 8 tools, all 0.4mm CHT; this is fixed and cannot be customized at order time. You can however add extra tools in other sizes to your order separately.

**What happens if a tool change fails mid-print?**

If a tool change fails, the printer errors out with a thermal error and the print is not recoverable.

**Is the induction heating safe? Any RF interference concerns?**

Yes. INDX has been tested and approved in accordance with Swedish law and the guidelines set by **Elsäkerhetsverket** (the Swedish National Electrical Safety Board), which is the authority responsible for electrical safety and electromagnetic compatibility (EMC) in Sweden. Elsäkerhetsverket enforces the EU Low Voltage Directive (LVD, 2014/35/EU) and the EMC Directive (2014/30/EU), which together require that electrical products are safe to use and neither cause nor are susceptible to electromagnetic interference.

The induction coil in the Smart Head operates at close range and low power, producing a highly localized magnetic field at the nozzle. It is not a transmitter in any meaningful sense; it does not emit RF energy across the room. EMC testing confirmed no interference with 3D printers, Wi-Fi networks, or other common equipment in the same space.

**Can I add more tools after initial setup?**

Yes. Additional Thin Passive Tools can be purchased and added at any time, from both Bondtech and Prusa.

For the **Development Kit**, the limit is physical dock space. There is no firmware cap; run as many tools as your printer can fit.

For the **Prusa CORE One / CORE One L kit**, both printers are physically limited to 8 tools maximum. You can purchase additional tools beyond what came in your kit, but you cannot exceed 8 installed tools on the printer.

**Does INDX work with Marlin?**

No. INDX requires Klipper, Kalico, or RepRap Firmware (RRF). Marlin is not supported.

**Can I set standby or preheat temperatures for parked tools?**

No. Passive tools contain no electronics; there is no way to heat a tool while it is sitting in the dock. Do not configure standby temperatures for individual tools in your slicer; the firmware has no way to act on them and it will produce errors.

**Is RRF (RepRapFirmware) supported?**

Yes. See the [Duet INDX Toolboard documentation](https://docs.duet3d.com/en/Duet3D_hardware/Duet_3_family/INDX_Toolboard) for RRF flashing and configuration, plus the [Firmware Configuration: RRF](#rrf-reprapfirmware) section. Ask on the [Bondtech Discord](https://discord.gg/XDX9jDXN6e) if you need help.

---

## Community & Contributing

The INDX ecosystem is built by the people running it. Bondtech maintains the core hardware and firmware, but the printer integrations, dock designs, part cooling solutions, and real-world usage guides come from community members who've done the work and shared it. If you've got INDX running, you're in a position to save the next person significant time.

- **Chat & community help:** [Bondtech Discord](https://discord.gg/XDX9jDXN6e), the best place for quick questions, sharing builds, and getting community support
- **Official support:** For issues with your hardware or order, submit a ticket at [bondtech.se/contact](https://www.bondtech.se/contact/)
- **CAD files & community configs:** [github.com/BondtechAB/INDX](https://github.com/BondtechAB/INDX)

### Contributing a printer integration

If you've integrated INDX with a printer that isn't in the repo yet, or significantly improved an existing integration, we want to hear from you. Merged PRs carry Bondtech's name alongside yours, so the bar is real: complete documentation, a clear setup guide, and files that others can actually use.

**What a good PR includes:**

- **Setup guide**: a written walkthrough of the full integration: mounting the Smart Head, routing cables, configuring the dock, and getting through initial calibration. It should be complete enough that someone starting from scratch can follow it without needing to ask for help.
- **Printer config**: a clean, working `printer.cfg` (or RRF equivalent) with INDX-specific sections clearly identified.
- **Dock design**: if you designed a custom dock, include the source files (STEP or similar) and any printable STLs. Printable files must be **designed to print without supports**, with overhangs addressed in the geometry, not worked around in the slicer.
- **X-carriage adapter**: if you designed or adapted one, include it with the same requirements.
- **Photos or video**: not required, but high-quality build photos or a video walkthrough of the installation process make the integration significantly more approachable. A good build guide video that shows the tricky parts is worth more than any amount of written description.

**What we look at before merging:**

Before a PR is merged, Bondtech will test the integration. What we're evaluating:

- **Print volume**: INDX always costs 28.5mm of Y-travel due to tool clearance. The integration must not lose more than that compared to a reference INDX build. Dock placement, cable routing, and any printed parts should be designed so that 28.5mm is the total loss, not a starting point. Exceeding it requires a compelling justification.
- **Tool count**: the design should support as many tools as the printer's build space allows. Leaving capacity on the table without a clear reason is a red flag.
- **Closeness to stock**: the fewer deviations from a standard build of that printer, the better. An integration that requires minimal modifications to the printer itself is easier to install, easier to maintain, and easier to recommend. Elegance here is rewarded.
- **User experience**: installation should be straightforward and the day-to-day experience of running the integration should be solid. Rough edges that could have been designed out should be designed out.

**How to submit:**

1. Fork [github.com/BondtechAB/INDX](https://github.com/BondtechAB/INDX)
2. Add your files under the appropriate printer folder (create one if it doesn't exist), following the structure of existing integrations
3. Open a pull request with a short summary of what you're contributing and what printer it covers

Not sure if your integration is ready? Share it on Discord first; the community can help you fill gaps before you submit.

---

*This wiki is community-maintained. Found an error or want to contribute? Open an issue or PR on [github.com/BondtechAB/INDX](https://github.com/BondtechAB/INDX) or ask on [Discord](https://discord.gg/XDX9jDXN6e).*

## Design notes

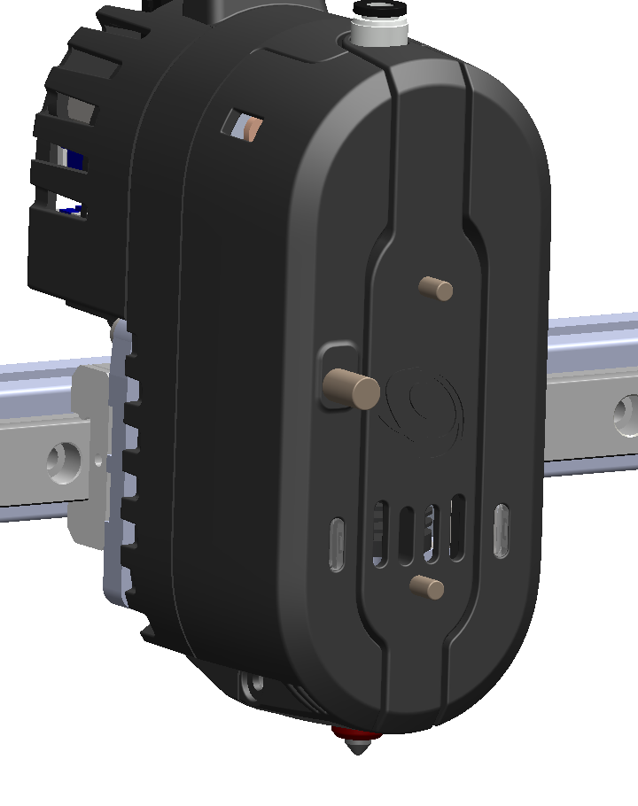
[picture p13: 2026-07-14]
images/dock-align-magnet-1.png

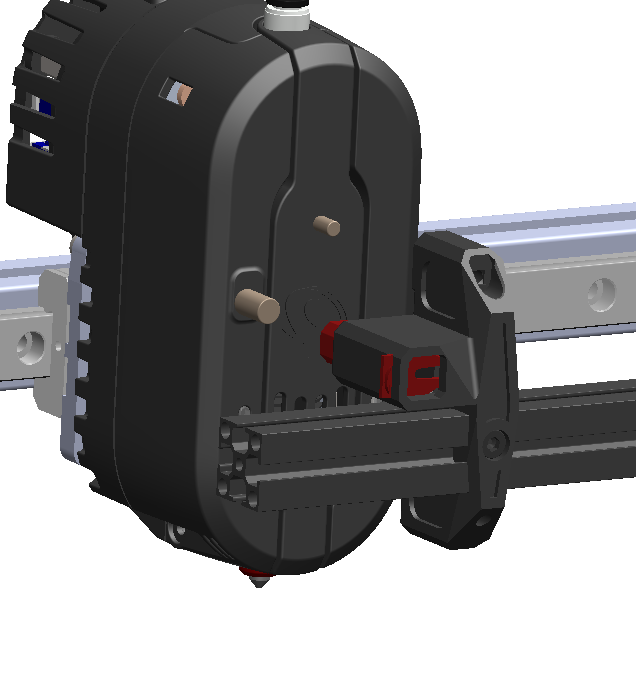
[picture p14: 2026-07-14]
images/dock-align-magnet-2.png

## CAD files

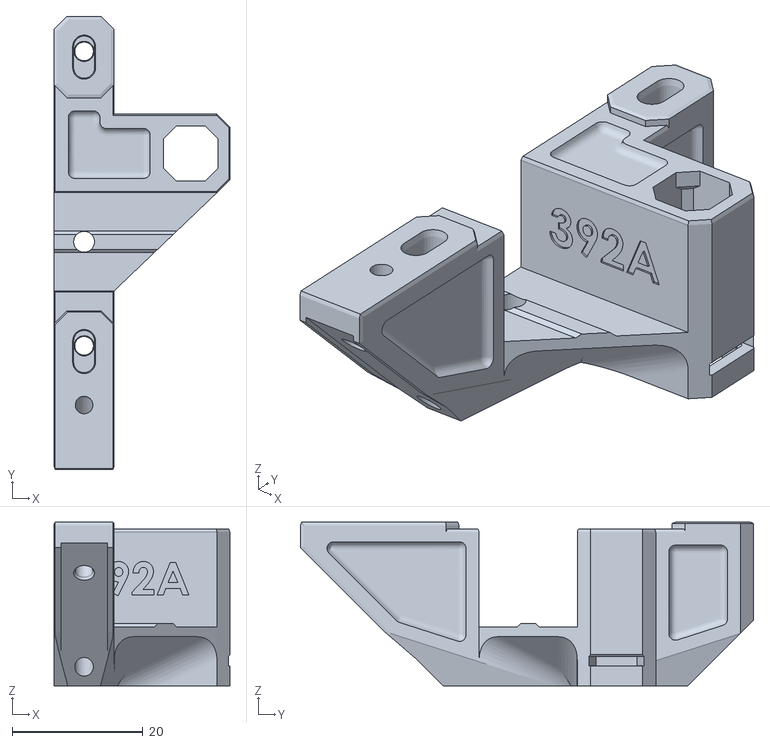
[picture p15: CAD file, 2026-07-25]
CAD/STL/INDX Tool Dock 1515 Main body.stl
26.9 x 69.3 x 25.0

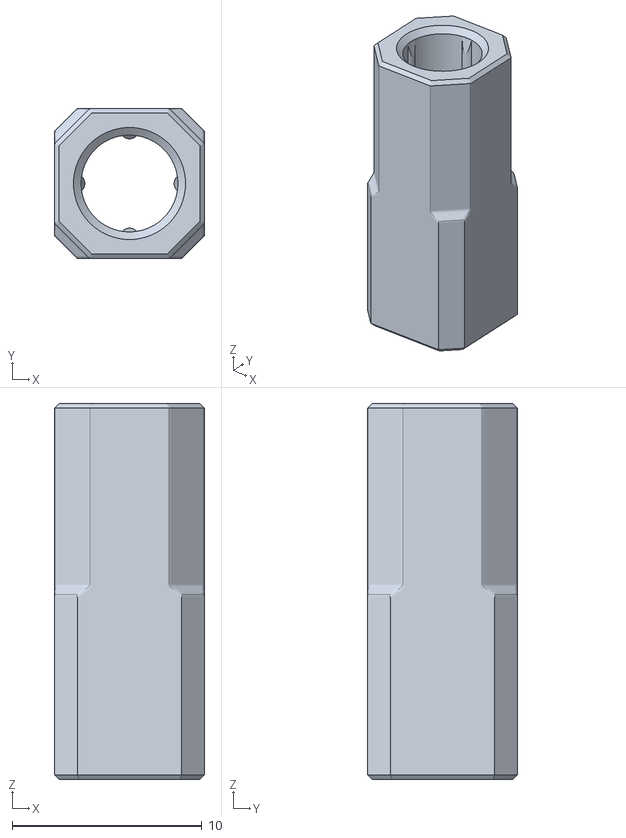
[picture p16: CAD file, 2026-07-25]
CAD/STL/INDX Tool Dock 1515 Magnet holder.STL
7.90 x 7.90 x 19.8

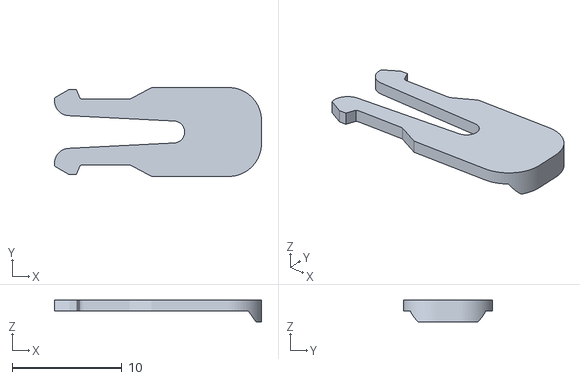
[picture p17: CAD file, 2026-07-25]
CAD/STL/INDX Tool Dock 1515 Spring lid.stl
18.9 x 8.10 x 2.00

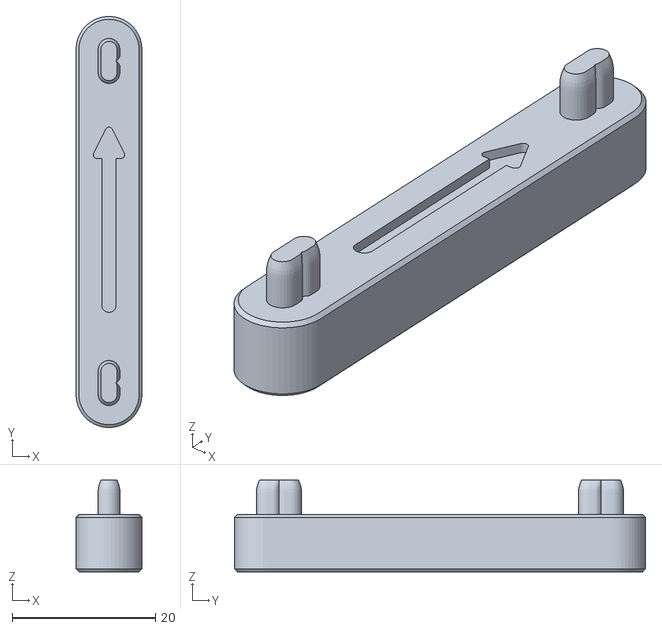
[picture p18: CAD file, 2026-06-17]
CAD/STL/INDX_Dock_calibration_tool.stl
9.20 x 57.4 x 12.8

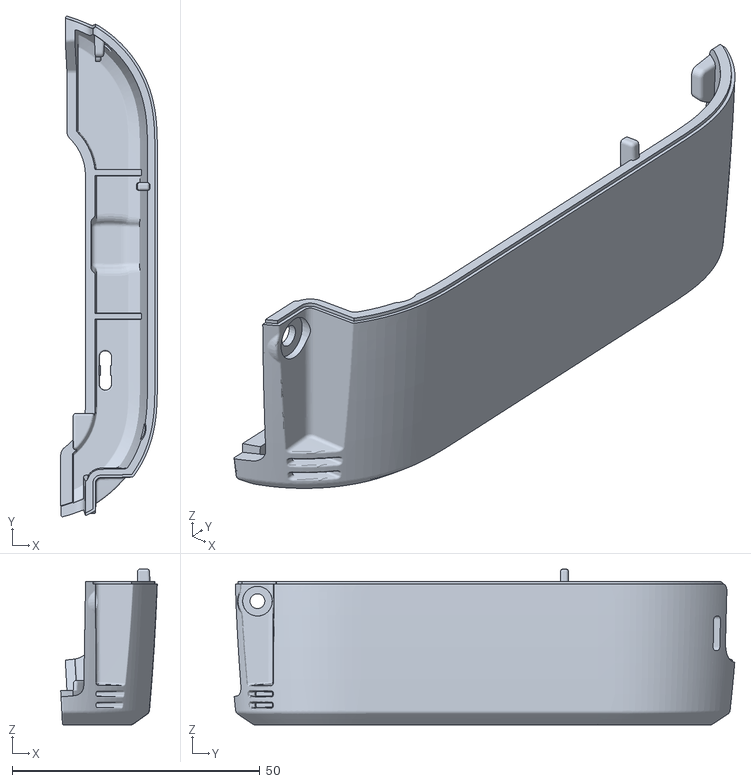
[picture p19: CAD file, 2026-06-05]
CAD/STL/INDX_Front_cover_left.stl
19.5 x 101.1 x 31.5

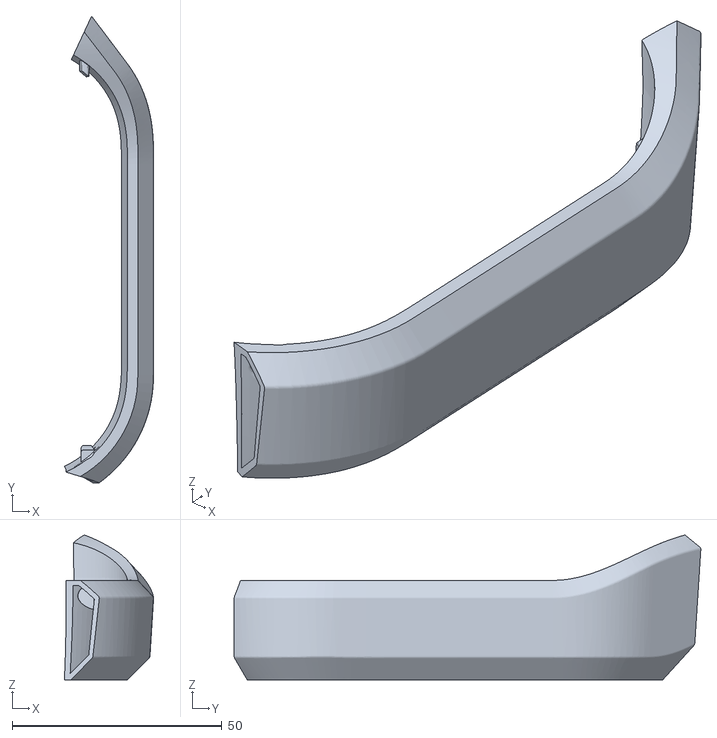
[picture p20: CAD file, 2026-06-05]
CAD/STL/INDX_CPAP_Duct_Left.stl
21.2 x 111.2 x 34.5

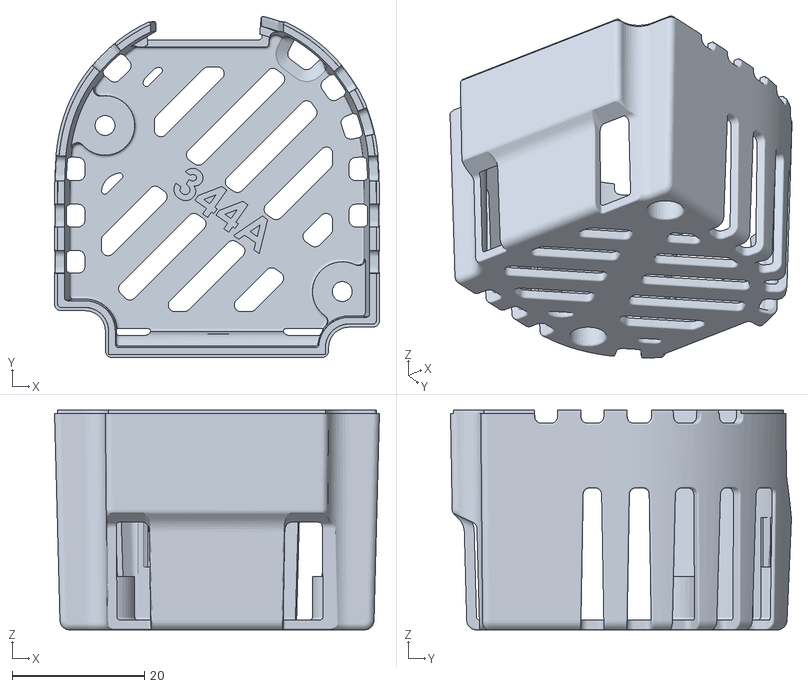
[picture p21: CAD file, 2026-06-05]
CAD/STL/INDX_PCB_Cover.stl
49.2 x 51.6 x 33.3

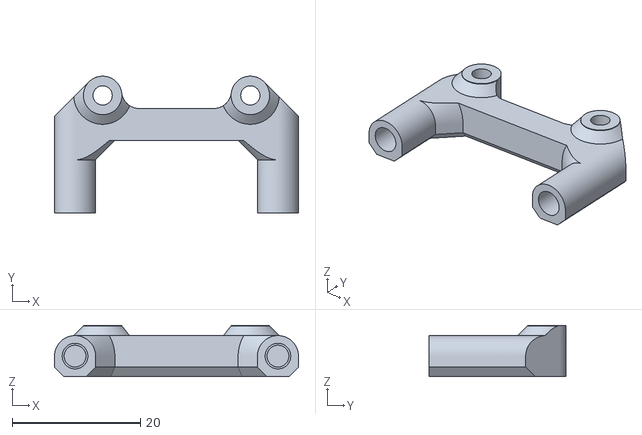
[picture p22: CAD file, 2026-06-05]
CAD/STL/INDX_Beacon_Cartographer_Mount.stl
38.0 x 21.3 x 7.99

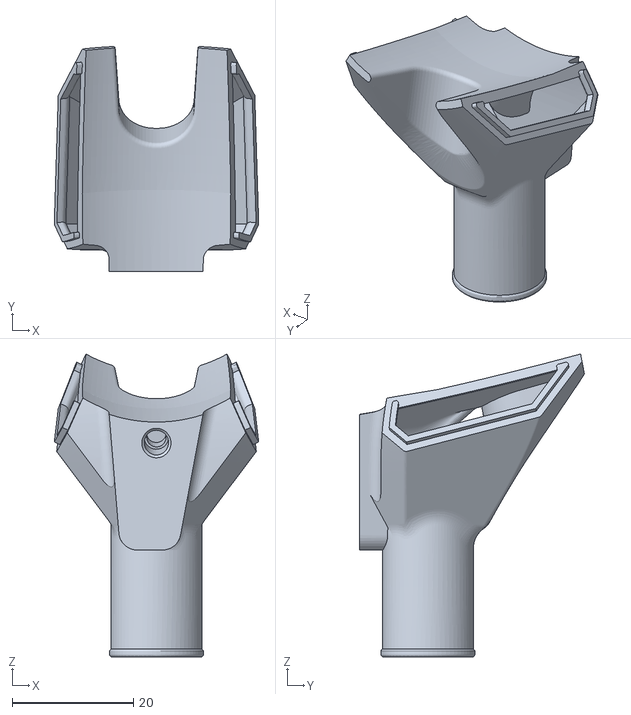
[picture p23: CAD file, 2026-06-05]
CAD/STL/INDX_CPAP_Duct_Top.stl
33.7 x 37.0 x 49.9

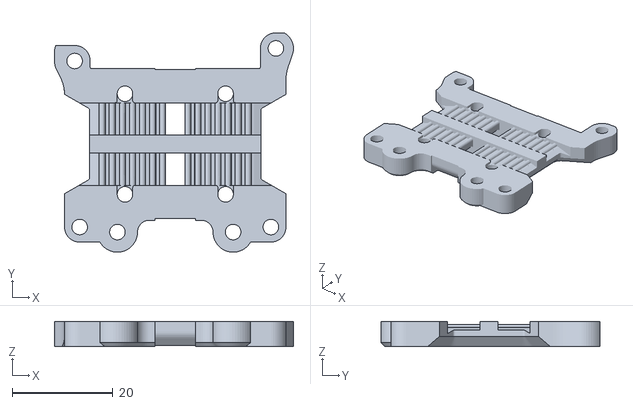
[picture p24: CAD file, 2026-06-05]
CAD/STL/INDX_MGN12H_X-carriage.stl
47.5 x 43.6 x 5.00

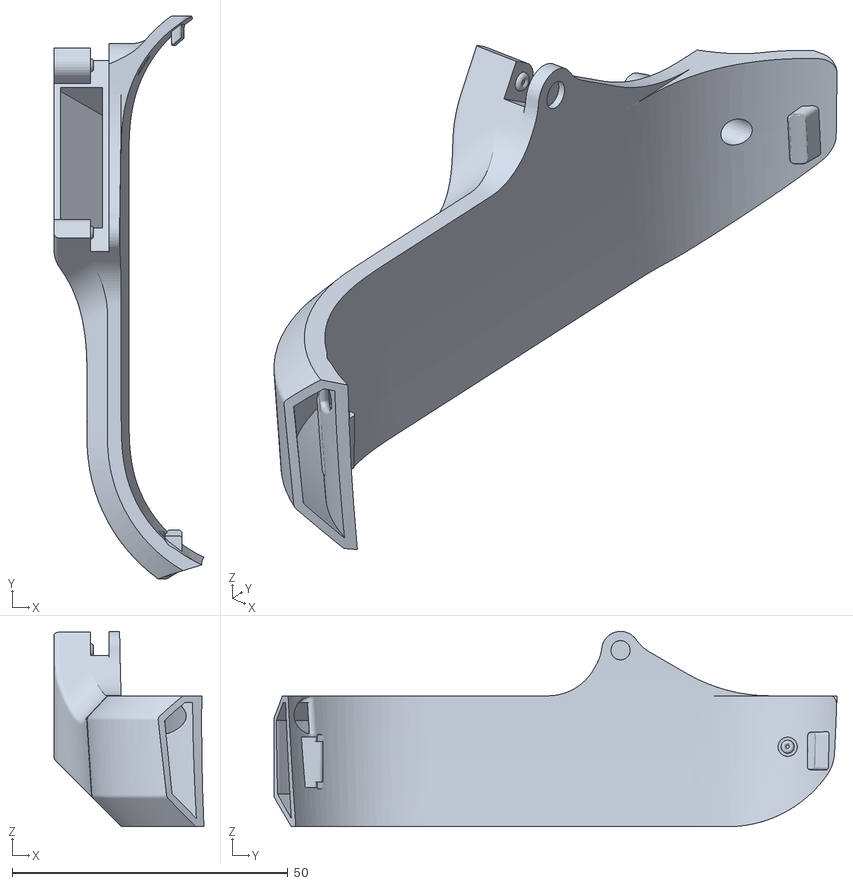
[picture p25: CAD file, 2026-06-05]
CAD/STL/INDX_4010_Duct_Right.stl
27.2 x 102.1 x 35.4

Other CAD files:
CAD/STL/INDX_Front_cover_right.stl
CAD/STL/INDX_CPAP_Duct_Right.stl
CAD/STL/INDX_4010_Duct_Left.stl

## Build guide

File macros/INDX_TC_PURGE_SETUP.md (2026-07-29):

# INDX purge-station setup guide

Calibrate `INDX_TC_VARS` in [`indx-tc-purge.cfg`](indx-tc-purge.cfg) so station enter, flush, brush, and exit stay inside soft limits and clear the wiper.

Live changes (lost on `RESTART` unless you edit the cfg):

```gcode
SET_GCODE_VARIABLE MACRO=INDX_TC_VARS VARIABLE=station_x VALUE=192.0
```

After a good set of numbers, copy them into `variable_*` in the cfg and `RESTART`.

---

## 0. Prerequisites

1. `[include indx-tc-purge.cfg]` is after your dock TC macros (`indx-tc-macros.cfg`).
2. Homing and `CHANGE_TOOL` / `T0` already work.
3. Know your soft limits (from `printer.cfg` / `position_min` / `position_max`, or console after home):
   - `GET_POSITION` (or Mainsail/Fluidd axis readouts)
   - Mentally: `X_min` … `X_max`, `Y_min` … `Y_max`, `Z_min` … `Z_max`
4. Keep a finger on emergency stop. First passes: cold nozzle, low travel speeds.

Useful console helpers:

```gcode
G28
GET_POSITION
INDX_TC_RETRACT STATE=query
```

`clear_y` used below is `TOOL_POSITIONS.clearance_y` if that macro exists, else `INDX_TC_VARS.clearance_y`.  
`dock_dir` is `TOOL_POSITIONS.dock_dir` if present, else `-1`.

---

## 1. Choose wipe axis

| Your wiper | Setting |
|---|---|
| Brush bristles / wipe stroke along **Y** (Prusa-like) | `wipe_along_x: 0` |
| Wipe stroke along **X** | `wipe_along_x: 1` |

```gcode
SET_GCODE_VARIABLE MACRO=INDX_TC_VARS VARIABLE=wipe_along_x VALUE=1
```

Flush wiggle, brush stroke, and eject jiggle follow this. Enter/exit still
use `clear_y` (dock clearance), not the wipe axis.

Also set `brush_x` / `brush_y` / spans in **machine coordinates** (true X and Y), not “rotated local” axes.

---

## 2. Safe Z first (`station_z` is a minimum)

1. Home, pick a tool (`CHANGE_TOOL TOOL=0`).
2. Jog XY over the purge/wipe area with Z high enough to clear everything.
3. Lower Z until the nozzle is at a comfortable purge height above the bin / brush (not touching).
4. Note that Z → `station_z`.

Behaviour: macros **only raise** Z to `station_z` when current Z is below it.
If the print is already at Z=45, station entry does **not** move Z down to 5.
Exit / `LAYER_Z` uses the same raise-only rule (never dive).

Checks:

- `station_z` must clear the brush tips and any bin lip when you *are* low.
- Optional `INDX_TC_POST ... LAYER_Z=` sets a raise-only resume floor (`+ resume_z_extra`).

Optional: temporarily lower `enter_feed` / `exit_feed` / `travel_speed` (e.g. 30–50 mm/s) while probing.

---

## 3. Set station centre (`station_x`, `station_y`)

This is where flush happens (bin / purge pot centre).

1. Jog to the centre of the purge area at `station_z`.
2. `GET_POSITION` → copy X into `station_x`, Y into `station_y`.
3. Confirm `clear_y` is on the **safe** side of the docks (same Y you use to travel past docks without clipping tools). If `TOOL_POSITIONS` is wrong, fix dock config; only then set `clearance_y` as a fallback.

Enter path (order matters):

1. Raise Z to at least `station_z` if needed  
2. `Y → clear_y` (at current X)  
3. `X → station_x` (at `clear_y`)  
4. `Y → station_y`  
5. `Z → station_z`

**Limit check for enter/exit alone:**

```text
X used: station_x   (plus whatever X you start from on the way to clear_y)
Y used: clear_y and station_y
```

Both must satisfy `Y_min ≤ y ≤ Y_max` and `X_min ≤ station_x ≤ X_max`.  
If the head starts at a dock X, the move `Y→clear_y` still uses that dock X - that X must be legal at `clear_y`.

---

## 4. Eject jiggle (along wipe stroke axis)

Runs immediately after arriving at the station, **before** the eject-temp
heat wait, so residue from the previous change is shaken off while it is
still solid enough to drop instead of smearing onto a warming nozzle.

| `wipe_along_x` | Positions |
|---|---|
| `0` | `Y = station_y` and `Y = station_y + dock_dir * eject_jiggle_dist` |
| `1` | `X = station_x` and `X = station_x + eject_jiggle_dir * eject_jiggle_dist` |

`eject_jiggle_dir` is `+1` or `-1` (default `-1`). Use it to shake toward the bin when wiping along X.

1. With nozzle at station, jog along the stroke axis a few mm toward the drop.
2. Set `eject_jiggle_dist` (start small, e.g. 3–5 mm) and `eject_jiggle_dir` if on X.
3. Limit check:

```text
# wipe_along_x=0
y_a = station_y
y_b = station_y + dock_dir * eject_jiggle_dist
Y_min ≤ min(y_a, y_b)  and  max(y_a, y_b) ≤ Y_max

# wipe_along_x=1
x_a = station_x
x_b = station_x + eject_jiggle_dir * eject_jiggle_dist
X_min ≤ min(x_a, x_b)  and  max(x_a, x_b) ≤ X_max
```

The other axis stays at the station coordinate during eject.

---

## 5. Flush wiggle (`flush_d_neg`, `flush_d_pos`)

Small moves along the **stroke** axis while extruding. Defaults ~1.3 / 1.5 mm are fine to start.

| `wipe_along_x` | Positions visited |
|---|---|
| `0` | `station_y - flush_d_neg` … `station_y + flush_d_pos` (X fixed) |
| `1` | `station_x - flush_d_neg` … `station_x + flush_d_pos` (Y fixed) |

Limit check: those endpoints must stay inside soft limits and inside the bin (not into the brush frame yet - brush is a later move).

---

## 6. Brush box (`brush_*`)

1. Jog the nozzle to the **centre** of the usable brush face → `brush_x`, `brush_y`.
2. Measure how far you can stroke along the wipe direction without leaving the brush or hitting hardware → that half-length is the stroke span:
   - Stroke along Y (`wipe_along_x=0`): set `brush_y_span` so full stroke is `2 * brush_y_span`
   - Stroke along X (`wipe_along_x=1`): set `brush_x_span` so full stroke is `2 * brush_x_span`
3. Measure how wide the brush is **perpendicular** to the stroke → that is the pass fan-out span (`brush_x_span` if wiping in Y, `brush_y_span` if wiping in X).
4. `brush_passes` (default 3): more passes spread across the pass span.

**Envelope formulas**

Let:

```text
half_pass = (brush_passes - 1) / (2 * brush_passes) * pass_span
```

(`half_pass = 0` when `brush_passes == 1`)

| `wipe_along_x` | Stroke | Pass span | X range | Y range |
|---|---|---|---|---|
| `0` | Y | `brush_x_span` | `brush_x ± half_pass` | `brush_y ± brush_y_span` |
| `1` | X | `brush_y_span` | `brush_x ± brush_x_span` | `brush_y ± half_pass` |

Require:

```text
X_min ≤ X_range_min  and  X_range_max ≤ X_max
Y_min ≤ Y_range_min  and  Y_range_max ≤ Y_max
```

Also leave a few mm margin inside soft limits; do not rely on endstop crash.

**Travel from station to brush:** the brush macro goes straight to the first brush corner/edge. Mentally check that the straight segment from `(station_x, station_y)` to the brush approach point does not clip the docks or bin walls. If it does, move `brush_*` or `station_*`, or raise Z (`station_z` is used for station work; brush currently stays at the Z left by the station - keep `station_z` high enough for the whole brush path).

---

## 7. Full post-TC XY box (before first hot run)

Compute the union (all numbers in mm):

```text
# Always
X candidates: station_x, brush X range from §6,
              (if wipe_along_x=1: station_x + eject_jiggle_dir * eject_jiggle_dist),
              (if wipe_along_x=1: flush X endpoints from §5)
Y candidates: clear_y, station_y,
              (if wipe_along_x=0: station_y + dock_dir * eject_jiggle_dist),
              (if wipe_along_x=0: flush Y endpoints from §5),
              brush Y range from §6
```

```text
X_min_post = min(all X candidates)
X_max_post = max(all X candidates)
Y_min_post = min(all Y candidates)
Y_max_post = max(all Y candidates)
```

Pass only if that box sits strictly inside soft limits (recommend ≥2–5 mm margin).

---

## 8. Speeds and heat (leave Prusa-ish until motion is proven)

| Variable | Role | First-test tip |
|---|---|---|
| `enter_feed` / `exit_feed` / `travel_speed` | XY travel | 30–60 mm/s until happy |
| `brush_feed` | Wipe speed | Slow enough not to deflect the brush mount |
| `eject_jiggle_feed` | Blob shake | Moderate |
| `purge_volume_mm3` | Flush volume | Keep 12 until flow looks right |
| `eject_temp_*` / `near_full_delta` | Staged heat | Defaults OK |

Retract / latch (do not treat as XY):

- Tip retract `post_purge_retract` (1.2) must stay **well under** latch unlock (~11 mm).
- `retract_toolchange` (8) is filament pull for deretract, not latch unlock.

---

## 9. Staged motion tests (cold → warm → full)

Do these in order. Abort on any unexpected move.

### A. Geometry only (no purge)

```gcode
G28
CHANGE_TOOL TOOL=0
# Optional: set station_* / brush_* live, then:
```

Jog-verify each pose you programmed (`station`, brush corners) with `G0`/`G1` at low F, or temporarily call helpers if you are comfortable:

- Mentally walk `_INDX_TC_GOTO_STATION` → eject (before heat) → flush → brush → exit Y.

There is no built-in dry-run dump of expanded G-code; use jog + the envelope maths in §7.

### B. Heat wait only

```gcode
CHANGE_TOOL TOOL=0
INDX_TC_POST TEMP=220 SKIP_PURGE
```

Confirms staging wait without station motion.

### C. First full station cycle (expect purge / ooze)

Nozzle at print temp, bin empty enough to catch filament:

```gcode
CHANGE_TOOL TOOL=0
INDX_TC_POST TEMP=220
```

Watch: enter via `clear_y`, flush on stroke axis, brush stroke direction, exit to `clear_y`, tip unretract if `unretract_after_exit=1`.

### D. Multi-tool line test

```gcode
INDX_TC_PURGE_TEST TEMP=220
```

Optional: `BED_TEMP=60`, `TOOLS=2` (only T0..T2), `LINE_LEN=120`, `LINE_GAP=15`, `SKIP_PURGE` for dock-only.

Also check the **bed line** box from the file header (centred on axis mid) does not hit clips or the wipe assembly.

### E. Slicer

Toolchange G-code:

```gcode
T{next_extruder}
M400
INDX_TC_POST TEMP={temperature[next_extruder]}
```

No second full heat-wait in the slicer. Slice a two-colour part and confirm first extrusion after each TC.

---

## 10. Persist and re-check after restart

1. Write final numbers into `variable_*` in `indx-tc-purge.cfg`.
2. `RESTART` (or firmware restart).
3. Re-run §7 arithmetic once (defaults must match what you jogged).
4. Re-run §9 C or D.

---

## Quick checklist

- [ ] `wipe_along_x` matches physical wiper
- [ ] `station_x/y/z` = purge centre / height
- [ ] `clear_y` / `TOOL_POSITIONS.clearance_y` safe past docks
- [ ] Eject endpoints along stroke axis inside limits and over the bin
- [ ] Flush endpoints inside bin
- [ ] Brush X/Y ranges inside limits and on bristles
- [ ] Full post-TC box inside soft limits with margin
- [ ] Tip retract ≪ latch unlock
- [ ] `SKIP_PURGE` OK → full `INDX_TC_POST` OK → `INDX_TC_PURGE_TEST` OK

XY envelope reference (same formulae) also lives in the header comment block of `indx-tc-purge.cfg`.

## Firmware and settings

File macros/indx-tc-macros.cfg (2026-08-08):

#####################################################################
#  INDX HARDWARE CONSTANTS
#####################################################################
#
#  These values are fixed by the INDX mechanism geometry and gear
#  mesh. DO NOT MODIFY unless you are changing the physical hardware.
#
#  Per-tool positions are derived as:
#     trigger_y   = tool.dock_y - TOOL_POSITIONS.dock_dir * trigger_offset
#     clearance_y = TOOL_POSITIONS.clearance_y                   (set in indx.cfg)
#
#####################################################################

[gcode_macro _INDX_CONSTANTS]
description: Fixed INDX hardware constants — do not modify

# --- Dock geometry ---
# Distance for the gentle peel-off after parking/pickup (relative move)
variable_peel_distance: 10.0

# --- Unlock dance: Y depths toward the dock from trigger_y ---
# These define the waypoints of the wiggle sequence.
# Expressed as positive distances along dock_dir from trigger_y.
variable_squeeze_depth: 0.5
variable_wiggle_in_depth: 1.0
variable_wiggle_out_depth: 2.0

# --- Unlock dance: E-axis moves (gear mesh — do not change) ---
variable_squeeze_e: -0.27
variable_wiggle_in_e: 0.27
variable_wiggle_out_e: -1.7
variable_full_open_e: -11.0
variable_full_lock_e: 11.0

# --- Feed rates (mm/min) ---
variable_squeeze_feedrate: 2000
variable_wiggle_feedrate: 2500
variable_dock_feedrate: 3000
variable_latch_feedrate: 1500
variable_peel_feedrate: 3000
# Fixed (not MODE-scaled) feeds for the final Y approach onto the tool.
# park_approach / approach = clearance -> trigger (park / pickup).
# engage = trigger -> dock (~trigger_offset mm) on pickup.
variable_park_approach_feedrate: 2500
variable_approach_feedrate: 2500
variable_engage_feedrate: 1800

# --- Extruder current (amps) ---
variable_squeeze_current: 0.2
variable_run_current: 0.6

# --- E-axis rotation distance for TC moves ---
# All E moves in the macros use this value regardless of what is set in printer.cfg.
# printer.cfg rotation_distance is restored after every macro that issues E moves.
variable_tc_rotation_distance: 5.7

# --- Load-cell tool presence ---
# Detect uses absolute grams vs empty-head reference: force_g + tare_force.
# Z probing re-tares the host cell, so raw force_g alone is wrong after home/probe.
# Cal may cinch to ~1600 g once; pickup uses full_lock_e only (no cinch like calibration).
# Normal-lock absolute preload is often below 1600; min ~400 fails closed on empty.
# Raise if false negatives; lower only with care (false positives heat an empty coil).
# VERIFY samples on the dock (peel-before-detect deferred). attempts = total
# samples per call (min 1), each separated by settle_ms; stop early on pass.
variable_tool_detect_enabled: 1
variable_tool_detect_min_force_g: 1000
variable_tool_detect_settle_ms: 250
variable_tool_detect_attempts: 3

gcode:

#####################################################################
#  1. GLOBAL VARIABLES & STATUS DASHBOARD
#####################################################################

[gcode_macro _TOOLCHANGE_VARS]
variable_mode: "normal"
variable_accel_mult: 0.7
variable_speed_mult: 0.7
variable_toolhead_state: 0 # 0=Locked, 2=Open
variable_rotation_dist_overridden: 0
# Set by [homing_override] so CHANGE_TOOL/PARK_TOOL do not re-enter G28 mid-home.
variable_homing_busy: 0
# XY TMC section prefix detected at boot (e.g. tmc2209, tmc5160). Empty = skip chopper writes.
variable_tmc_prefix: ""
gcode:

[delayed_gcode INIT_STATE]
initial_duration: 5.0
gcode:
    # Build the tools list from the numbered variables in TOOL_POSITIONS
    {% set tp = printer["gcode_macro TOOL_POSITIONS"] %}
    {% set ns = namespace(json="") %}
    {% for i in range(tp.tool_count|int) %}
        {% set x  = tp["t" ~ i ~ "_x"]|float %}
        {% set dy = tp["t" ~ i ~ "_dock_y"]|float %}
        {% set entry = '{"x": %.3f, "dock_y": %.3f}' % (x, dy) %}
        {% if loop.first %}
            {% set ns.json = "[" ~ entry %}
        {% else %}
            {% set ns.json = ns.json ~ ", " ~ entry %}
        {% endif %}
    {% endfor %}
    SET_GCODE_VARIABLE MACRO=TOOL_POSITIONS VARIABLE=tools VALUE='{ns.json}]'

    {% set sv = printer.save_variables.variables %}
    # Restore saved latch state so INDX displays the correct Open/Locked label after a
    # firmware restart. The INDX latch is mechanically self-retaining, so the saved value
    # accurately reflects the physical position across restarts.
    # Defaults to 0 (Locked) on first boot before any toolchange has been recorded.
    SET_GCODE_VARIABLE MACRO=_TOOLCHANGE_VARS VARIABLE=toolhead_state VALUE={sv.toolhead_state|default(0)|int}

    # Detect XY TMC driver family once so MODE_* can write the correct chopper field
    # (en_spreadcycle on 2208/2209, en_pwm_mode on 2130/2240/5160) including AWD x1/y1.
    {% set cfg = printer.configfile.settings %}
    {% set tmc_prefixes = ["tmc2209", "tmc2208", "tmc2240", "tmc2130", "tmc5160"] %}
    {% set xy_steppers = ["stepper_x", "stepper_x1", "stepper_y", "stepper_y1"] %}
    {% set tmc_ns = namespace(prefix="") %}
    {% for stepper in xy_steppers %}
        {% if tmc_ns.prefix == "" %}
            {% for prefix in tmc_prefixes %}
                {% if tmc_ns.prefix == "" and (prefix ~ " " ~ stepper) in cfg %}
                    {% set tmc_ns.prefix = prefix %}
                {% endif %}
            {% endfor %}
        {% endif %}
    {% endfor %}
    SET_GCODE_VARIABLE MACRO=_TOOLCHANGE_VARS VARIABLE=tmc_prefix VALUE='"{tmc_ns.prefix}"'

    {% set mode = sv.tc_mode|default("normal") %}
    {% if mode == "custom" %}
        MODE_CUSTOM ACCEL={sv.tc_custom_accel} SPEED={sv.tc_custom_speed}
    {% else %}
        MODE_{mode|upper}
    {% endif %}
    TOOL_STATUS

[gcode_macro TOOL_STATUS]
gcode:
    {% set sv = printer.save_variables.variables %}
    {% set tp = printer["gcode_macro TOOL_POSITIONS"] %}
    {% set st = printer["gcode_macro _TOOLCHANGE_VARS"].toolhead_state|int %}
    {% set mode = printer["gcode_macro _TOOLCHANGE_VARS"].mode|upper %}
    {% set state_label = "🔒 LOCKED" if st == 0 else "🔓 OPEN" %}
    RESPOND MSG="----------------------------------------"
    RESPOND MSG="  ⚙️ SPEED MODE:  {mode}"
    RESPOND MSG="  🔐 LOCK STATE:  {state_label}"
    RESPOND MSG="  🔧 TOOLS:       {tp.tools|length} configured"
    RESPOND MSG="  📦 ACTIVE TOOL: {('T' ~ sv.active_tool if sv.active_tool|default(-1)|int >= 0 else 'NONE')}"
    RESPOND MSG="  🔄 TC COUNT:    {sv.toolchange_count|default(0)|int}"
    {% set vd = printer["gcode_macro VERIFY_TOOL_PRESENT"] %}
    {% if vd.last_ok|int == 1 %}
        RESPOND MSG="  ⚖️ TOOL DETECT: ok ({'%.1f'|format(vd.last_force_g|float)}g)"
    {% elif vd.last_ok|int == 0 %}
        RESPOND MSG="  ⚖️ TOOL DETECT: fail ({'%.1f'|format(vd.last_force_g|float)}g)"
    {% endif %}
    RESPOND MSG="----------------------------------------"
    RESPOND MSG="  🛠️ INDX STATUS"
    RESPOND MSG="----------------------------------------"

[gcode_macro INDX]
gcode: TOOL_STATUS

[gcode_macro INDX_FORCE_STATE]
description: Soft-state only. Set ACTIVE_TOOL=n (-1 = none). Does not move the latch or apply offsets.
gcode:
    {% if "ACTIVE_TOOL" not in params %}
        {action_raise_error("Usage: INDX_FORCE_STATE ACTIVE_TOOL=<n|-1>")}
    {% endif %}
    {% set t = params.ACTIVE_TOOL|int %}
    {% set n = printer["gcode_macro TOOL_POSITIONS"].tool_count|int %}
    {% if t < -1 or t >= n %}
        {action_raise_error("ACTIVE_TOOL=%d out of range (-1..%d)"|format(t, n - 1))}
    {% endif %}
    SAVE_VARIABLE VARIABLE=active_tool VALUE={t}
    RESPOND MSG="INDX_FORCE_STATE: active_tool={'NONE' if t < 0 else ('T' ~ t)}"

[gcode_macro INDX_UNLOCK]
description: Open the latch in place (no dock dance). Updates lock soft-state to Open.
gcode:
    {% set c = printer["gcode_macro _INDX_CONSTANTS"] %}
    _TC_SET_ROTATION_DIST
    _TC_LATCH_MOVE E={c.full_open_e} F={c.latch_feedrate} I={c.run_current}
    _TC_RESTORE_ROTATION_DIST
    SET_GCODE_VARIABLE MACRO=_TOOLCHANGE_VARS VARIABLE=toolhead_state VALUE=2
    SAVE_VARIABLE VARIABLE=toolhead_state VALUE=2
    RESPOND MSG="INDX_UNLOCK: latch open"

[gcode_macro INDX_LOCK]
description: Close the latch in place. Updates lock soft-state to Locked.
gcode:
    {% set c = printer["gcode_macro _INDX_CONSTANTS"] %}
    _TC_SET_ROTATION_DIST
    _TC_LATCH_MOVE E={c.full_lock_e} F={c.latch_feedrate} I={c.run_current}
    _TC_RESTORE_ROTATION_DIST
    SET_GCODE_VARIABLE MACRO=_TOOLCHANGE_VARS VARIABLE=toolhead_state VALUE=0
    SAVE_VARIABLE VARIABLE=toolhead_state VALUE=0
    RESPOND MSG="INDX_LOCK: latch locked"

#####################################################################
#  2. SPEED & POWER MODES
#####################################################################
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

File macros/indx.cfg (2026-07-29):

#####################################################################
#  INDX USER CONFIGURATION
#####################################################################
#
#  This is the ONLY file you need to edit to adapt INDX to your
#  machine. All other INDX config files derive their values from
#  the variables defined here.
#
#  HOW TO CONFIGURE TOOLS:
#    Set tool_count to the number of tools installed.
#    Then fill in one pair of variables per tool (tN_x, tN_dock_y).
#       x      — X coordinate centred on the tool holder (mm)
#       dock_y — Y coordinate where the tool is fully seated (mm)
#                (deeper into the dock along dock_dir)
#
#    Tool number = variable suffix.  t0 = T0, t1 = T1, etc.
#    Add or remove pairs and update tool_count — the system adapts automatically.
#
#  WHAT IS AUTO-DERIVED:
#    - Trigger Y per tool (dock_y - dock_dir * trigger_offset)
#
#  WHAT NOT TO TOUCH:
#    - E-axis moves and dance geometry are fixed hardware constants
#      defined in indx-tc-macros.cfg. These are determined by the
#      INDX mechanism and must not be changed.
#
#####################################################################

[gcode_macro TOOL_POSITIONS]
description: INDX tool positions (user-configurable)

# ── How many tools are installed ─────────────────────────────────────────────
variable_tool_count: 3

# ── Z-hop during toolchange ──────────────────────────────────────────────────
#  z_hop = distance (mm) to raise Z during the first XY toolchange move.
#          Non-blocking: Z rises while XY travel to the dock, and descends
#          while XY sprint back to clearance after pickup (one combined move).
#          Set to 0.0 to disable.
variable_z_hop: 1.0

# ── Z offset auto-calibration probe position ─────────────────────────────────
#  Used by CAL_Z_AUTO_ALL to probe each tool and calibrate Z offsets.
#
#  probe_x / probe_y  — centre of the probing area (machine coords, mm).
#                       Set to the centre of your bed. The macro will probe
#                       here for debris clearing, then +5 mm in X for the
#                       actual measurement.
#  probe_fuzz         — legacy fuzz radius, kept for compatibility (mm).
#  probe_z_clearance  — Z height (gcode space) the toolhead travels to before
#                       descending to probe. Must clear any bed features.
variable_probe_x:          -1.0   # set to bed centre X, or -1 to auto-detect
variable_probe_y:          -1.0   # set to bed centre Y, or -1 to auto-detect
variable_probe_fuzz:         2.0
variable_probe_z_clearance: 10.0

# ── Dock approach direction ──────────────────────────────────────────────────
#  dock_dir = Y sign into the dock: -1 front (min Y), +1 rear (max Y).
#             Flips trigger line, unlock depths, and peel relative to dock_y.
variable_dock_dir: -1

# ── Trigger offset ───────────────────────────────────────────────────────────
#  trigger_offset = distance (mm) from dock_y to the trigger line.
#                   trigger_y is auto-derived as: dock_y - dock_dir * trigger_offset
#                   Increase if the latch engages before the tool is fully seated;
#                   decrease if the toolhead overshoots the dock.
variable_trigger_offset: 5.0

# ── Safe lateral travel position ─────────────────────────────────────────────
#  clearance_y = Y coordinate where the toolhead clears ALL docked tools.
#                The toolhead moves here before any X travel between tools.
#                Set this to the Y position where no tool bodies are in the way.
variable_clearance_y: 0.0

# ── Per-tool positions ────────────────────────────────────────────────────────
#  x      = X coordinate of the tool holder centre (mm)
#  dock_y = Y coordinate where the tool is fully seated (mm)
#           Move further along dock_dir to seat the tool deeper.
#
#  To add a tool:    add a new pair of lines and increment tool_count above.
#  To remove a tool: delete its pair of lines and decrement tool_count above.
#
variable_t0_x:       0.0
variable_t0_dock_y: -26
#
variable_t1_x:      43.70
variable_t1_dock_y: -26
#
variable_t2_x:      88.70
variable_t2_dock_y: -26
#
variable_t3_x:     102.0
variable_t3_dock_y: -26

# ── Assembled at startup from the variables above — do not edit ──────────────
variable_tools: []

gcode:

#####################################################################
#  TOOL SHORTCUT MACROS (T0–T3)
#####################################################################
#  Slicers send T0, T1, etc. to select tools. Each macro below
#  routes to CHANGE_TOOL, which validates the index against the
#  tools list above and errors cleanly if the tool doesn't exist.
#
#  Optional params are forwarded: TEMP= / TARGET= (early reheat after
#  lock), SKIP_Z_CORRECTION=1 (calibration). Example slicer snippet:
#    T{next_extruder} TEMP={temperature[next_extruder]}
#
#  If you have more than 4 tools, add more entries following the
#  same pattern.
#####################################################################

[gcode_macro T0]
gcode:
    CHANGE_TOOL TOOL=0{% if 'TEMP' in params %} TEMP={params.TEMP}{% endif %}{% if 'TARGET' in params %} TARGET={params.TARGET}{% endif %}{% if 'SKIP_Z_CORRECTION' in params %} SKIP_Z_CORRECTION={params.SKIP_Z_CORRECTION}{% endif %}
[gcode_macro T1]
gcode:
    CHANGE_TOOL TOOL=1{% if 'TEMP' in params %} TEMP={params.TEMP}{% endif %}{% if 'TARGET' in params %} TARGET={params.TARGET}{% endif %}{% if 'SKIP_Z_CORRECTION' in params %} SKIP_Z_CORRECTION={params.SKIP_Z_CORRECTION}{% endif %}
[gcode_macro T2]
gcode:
    CHANGE_TOOL TOOL=2{% if 'TEMP' in params %} TEMP={params.TEMP}{% endif %}{% if 'TARGET' in params %} TARGET={params.TARGET}{% endif %}{% if 'SKIP_Z_CORRECTION' in params %} SKIP_Z_CORRECTION={params.SKIP_Z_CORRECTION}{% endif %}
[gcode_macro T3]
gcode:
    CHANGE_TOOL TOOL=3{% if 'TEMP' in params %} TEMP={params.TEMP}{% endif %}{% if 'TARGET' in params %} TARGET={params.TARGET}{% endif %}{% if 'SKIP_Z_CORRECTION' in params %} SKIP_Z_CORRECTION={params.SKIP_Z_CORRECTION}{% endif %}
[gcode_macro T4]
gcode:
    CHANGE_TOOL TOOL=4{% if 'TEMP' in params %} TEMP={params.TEMP}{% endif %}{% if 'TARGET' in params %} TARGET={params.TARGET}{% endif %}{% if 'SKIP_Z_CORRECTION' in params %} SKIP_Z_CORRECTION={params.SKIP_Z_CORRECTION}{% endif %}

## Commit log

2026-06-17 Update printer requirements in README
    Clarified unsupported motion systems in printer requirements.
2026-06-18 Updated nozzle sizes
2026-07-14 Updated readme, added macros
    These macros are largely tested, but please submit any tickets for unexpected behavior or bugs.
    [indx-cal.cfg, indx-tc-macros.cfg, indx.cfg]
2026-07-18 feat: dock_dir variable to cleanly support min and max y position (front and back) mounted tool racks
    [indx-cal.cfg, indx-tc-macros.cfg, indx.cfg]
2026-07-22 feat: squash INDX macro improvements from all branches
    - Load cell tool presence detect, homing override, print fail recovery
    - dock_dir for front/rear docks; dock_y cal and docs sync
    - require TOOL= on CHANGE_TOOL and dock X cal macros
    - honor SKIP_Z_CORRECTION in pickup finish
    - CAL_Z: default t0_offset_z; lift before finalize park
    - camera goto fail-closed without CAL_01 refs
    [homing.cfg, indx-cal.cfg, indx-tc-macros.cfg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]
2026-07-22 fix(load-filament): use ±3C temp wait tolerance
    MINIMUM={temp} could hang when the extruder settled just below target.
    Match print_start and accept temp within ±3C before feeding.
    [indx-cal.cfg]
2026-07-22 revert pickup fan feature
    [indx-tc-macros.cfg]
2026-07-22 fix(macros): peel away from dock under Jinja {-
    {-(expr)} is parsed as whitespace-strip, so front-dock peel
    became Y-10 into the dock and tripped position_min.
    [indx-cal.cfg, indx-tc-macros.cfg]
2026-07-23 fix - stop holding the tool prisoner after CALIBRATE_LOAD_CELL_APPLY
    [indx-cal.cfg]
2026-07-23 fix: indx-cal.cfg - clarify tool empty requirements
    [indx-cal.cfg]
2026-07-23 fix: readme - clarify requirements for tool calibration
2026-07-23 fix: macros - clarify homing sequence and conditions
    [homing.cfg, print_start.cfg]
2026-07-23 feat: macros - add safe Z hop before lateral travel
    [homing.cfg]
2026-07-23 fix Y before X handling
    [homing.cfg]
2026-07-23 fix: macros - improve clarity in homing sequence
    [homing.cfg]
2026-07-23 fix: macros - update homing sequence comments for clarity
    [homing.cfg]
2026-07-23 align homing.cfg with upstream readme sequence
    [homing.cfg]
2026-07-23 add load cell tool detection
    [indx-helpers.cfg, indx-tc-macros.cfg]
2026-07-23 remove pickup fan letfovers
    [indx-helpers.cfg, indx-tc-macros.cfg]
2026-07-24 fix: macros - update temperature handling in print_start
    [print_start.cfg]
2026-07-25 fix: macros - improve Z homing tool verification
    [homing.cfg]
2026-07-25 fix: macros - adjust temperature command placement so no error when beginning with tool=-1
    [print_start.cfg]
2026-07-26 fix: macros - streamline tool change parameters handling
    [VZBOT_INDX.machine.json, indx-tc-macros.cfg, indx-tc-purge.cfg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]
2026-07-26 fix: macros - m104.cfg inclusion for slicer "extruder not configured error"
    [m104.cfg, m109.cfg]
2026-07-27 fix: macros - update GOTO_STATION for brush XY travel and reverse d_neg d_pos
    [indx-tc-purge.cfg]
2026-07-27 fix: macros - adjust station and brush geometry values
    [indx-tc-purge.cfg]
2026-07-27 working purge
    [indx-tc-purge.cfg]
2026-07-27 fix: macros - update feed rates for travel commands
    [indx-tc-purge.cfg]
2026-07-27 fix: macros - adjust purge volume and locking behaviour
    [indx-tc-purge.cfg]
2026-07-27 feat: macros - add custom toolchange mode with parameters
    [indx-tc-macros.cfg, indx-tc-purge.cfg, indx.cfg]
2026-07-27 feat: macros - implement INDX_TC_UNRETRACT for tip control
    [indx-tc-purge.cfg]
2026-07-28 fix: macros - update post purge retract values
    [VZBOT_INDX.machine.json, indx-tc-macros.cfg, indx-tc-purge.cfg]
2026-07-28 fix: macros - lock approach and engage feed rates Add attempts / retries to VERIFY_TOOL_PRESENT
    [indx-tc-macros.cfg]
2026-07-28 fix: macros - refine PRINT_START sequence and logic
    [print_start.cfg]
2026-07-29 fix: macros - improve CHANGE_TOOL logic for Z-hop
    [print_start.cfg]
2026-07-29 Home with any tool
    [homing.cfg, indx-cal.cfg, indx-tc-macros.cfg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]
2026-07-29 fix: macros - Z homing tool verification reading stale state
    [homing.cfg]
2026-07-29 fix(macros): slow TPU guided filament load
    LOAD_FILAMENT TYPE=TPU used the default 10 mm/s feed (~24 mm3/s),
    which can buckle soft filament into the Smart Head. Pass preset
    speed 2 mm/s to INDX_LOAD_FILAMENT for TPU.
    [indx-cal.cfg]
2026-07-29 docs: readme - document Mainsail RESUME coexistence
    [indx-helpers.cfg]
2026-07-29 fix: macros - keep VERIFY/RESUME only in helpers after merge
    Home-z merge reintroduced detect macros in tc-macros beside helpers.
    Dedupe into indx-helpers (retries + Mainsail RESUME) and fix duplicate T3.
    [indx-helpers.cfg, indx-tc-macros.cfg, indx.cfg]
2026-07-29 chore: stop tracking slicer profiles and DS_Store
    Slicer machine/process files stay local; keep them out of the macro repo.
    [VZBOT_INDX.machine.json]
2026-08-08 fix: macros - use correct TMC chopper field on MODE_*
    en_spreadcycle only exists on TMC2208/2209; other XY drivers need
    en_pwm_mode with inverted polarity. Detect the driver once at boot
    and apply it to all present XY steppers including AWD x1/y1.
    [indx-tc-macros.cfg]
